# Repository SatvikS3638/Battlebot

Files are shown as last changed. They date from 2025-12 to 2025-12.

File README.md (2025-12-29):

# Project Overview

This project documents the design of a 15 kg combat robot (battlebot) for Robowars‑style competitions, focusing on mechatronic system design, drivetrain sizing, weapon actuation, and electrical subsystem selection. The goal was to design a robust, remotely operated, two‑wheeled drum‑spinner robot that can traverse the arena quickly, survive impacts, and reliably deliver weapon strikes within the competition budget and rules.

This project is hosted at : [https://github.com/SatvikS3638/Battlebot]

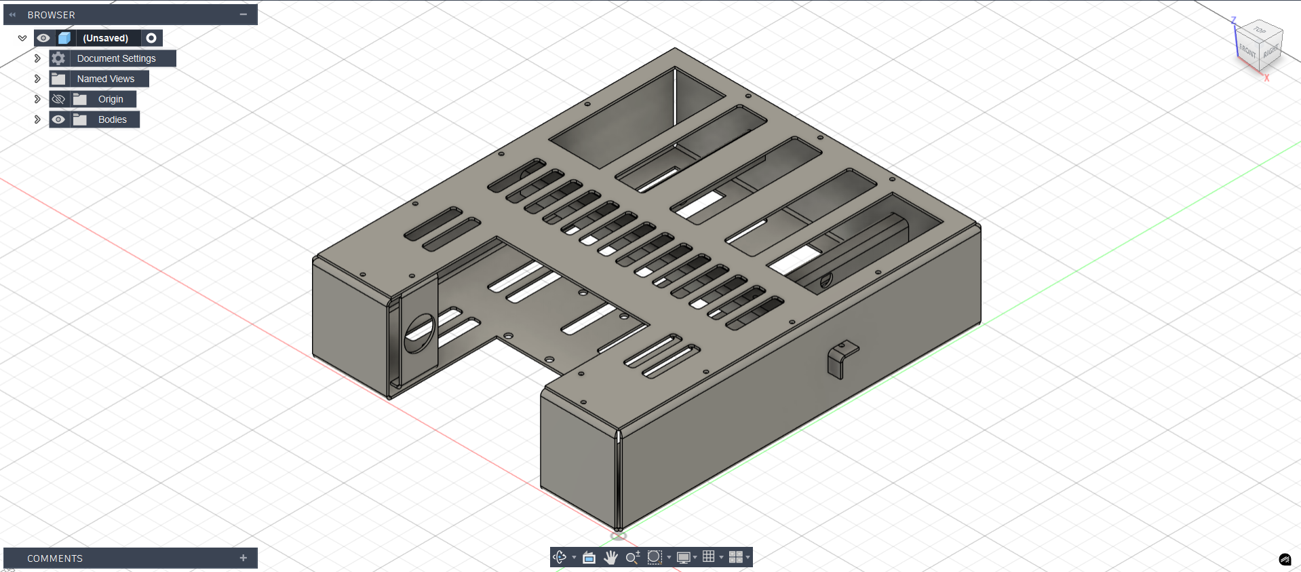
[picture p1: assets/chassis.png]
Combat Robot Chassis
 

# System Requirements
## Competition and Performance Targets
* Maximum robot weight: 15 kg (Robowars class limit).
* Locomotion: Two‑wheel differential drive with independent wheel motors.
* Weapon: Front‑mounted horizontal drum spinner capable of delivering high‑energy impacts.
* Mobility target: Traverse the arena diagonal (approximately 16 ft) in about 6 seconds, with adequate acceleration for combat maneuvers.

## Mechanical Constraints
* Maximum practical wheel diameter identified from available COTS wheels: 100 mm (10 cm).
* Wheel width options considered: approximately 20 mm and 46 mm, chosen for robustness and traction in a combat environment.
* Drum spinner radius constrained to be no larger than wheel radius (≈50 mm) to maintain ground clearance and packaging compatibility

## Electrical and Control Constraints
* Remote control via RC transmitter–receiver pair with at least 3 channels (2 drive channels + 1 weapon channel).
* Power system using LiPo chemistry for high discharge rates and low weight.
* Use of COTS ESCs or motor drivers compatible with selected brushed/brushless motors and current requirements.

# Drivetrain Design
## Velocity and RPM Calculations
To ensure adequate mobility, the required linear speed V was computed assuming the robot must cross the diagonal of the arena in about 6 seconds. For a 16 ft square arena, this yields a required velocity of approximately 1.15 m/s. 
For a wheel radius R ≈ 0.05 m (10 cm diameter), the required wheel rotational speed N is: 
$$N=\frac{V}{2\pi R}≈7.32rev/s≈220rpm$$ 

This RPM served as a target for the wheel motor selection so that the bot can meet the agility requirement without over‑gearing the drivetrain.

## Acceleration Requirement
Typical combat robot guidelines suggest an acceleration magnitude on the order of half the target velocity over one second. Using this rule of thumb, a design acceleration of approximately 0.57 m/s² was adopted for sizing the drivetrain torque.

## Traction and Torque Estimates
Assuming a maximum robot weight of 15 kg and a worst‑case engagement where the effective load on the wheels can temporarily double (up to 30 kg), the load per wheel was estimated at about 7.5 kg for a four‑wheel configuration. Using this load and the 50 mm wheel radius, the static torque requirement per wheel was computed as approximately 0.375 Nm (37.5 Ncm).
To provide a robust margin, an additional rule from combat robotics practice was applied: each drive motor’s stall torque should be sufficient to lift the full robot weight at the wheel radius. Using a 15 kg robot, the required stall torque per motor becomes:
$$T_{stall}=mgr=15x9.8x0.05≈7.35Nm$$
This requirement drove the choice of geared drive motors with sufficiently high stall torque.

## RMF (Robot Motor Factor) Check
The drivetrain design was validated using an online Robot Motor Factor (RMF) calculator, which consolidates robot weight, wheel radius, and speed into a single metric. With the chosen parameters, the RMF requirement was around 6.9 kg·m·rev/s, and motors meeting or exceeding this RMF were considered acceptable.

# Weapon (Drum Spinner) Design

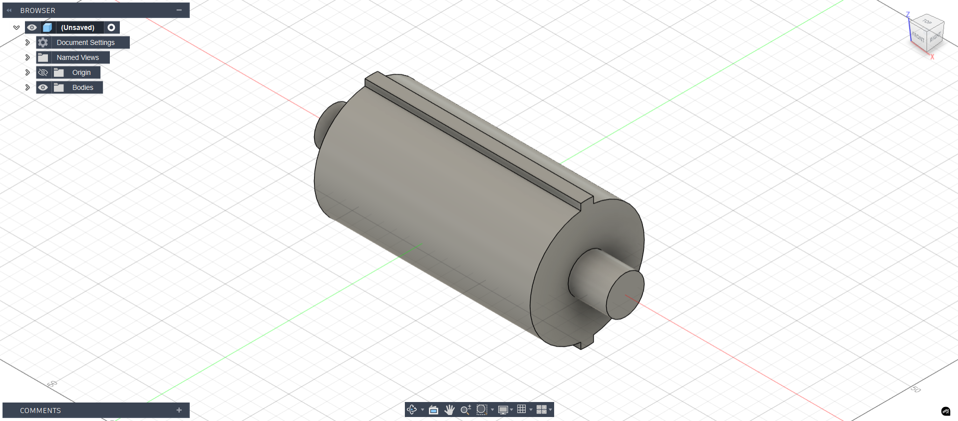
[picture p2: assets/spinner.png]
Drum Spinner Design
 

## Worst‑Case Load Modelling
The drum spinner motor was sized for an extreme case where the entire opponent robot’s weight rests on the drum, even though this scenario is unlikely in practice. Taking an opponent mass of up to 15 kg and assuming a friction coefficient up to 1, the maximum normal force on the drum can be approximated as:
$$F_{max}≈2xM_{2}g≈294N$$
Here, a safety factor of 2 was included to account for dynamic impacts and uncertainties.
With the drum radius constrained to 50 mm, the corresponding resistive torque is:
$$T_{drum}=F_{max}xr≈294x0.05≈14.7Nm$$
This torque is intentionally conservative; in practice, such a load is rarely sustained, so the design decision was to select a “very high torque” motor and prioritize robustness rather than exactly meeting this extreme torque.

## Motor Selection Strategy
The primary criteria for the drum motor were:
* High torque at operating speed to spin up the drum quickly and resist stalling during impact.
* Thermal robustness so that the motor does not overheat or fail under repeated high‑torque, high‑current operation.
* Compatibility with available ESCs and supply voltage (around 11–12 V), and alignment with overall budget limits.

# Electronics and Control System
## Motor Control (ESCs and Drivers)
For brushless motors, compact drone‑type ESCs rated at 40 A and above were considered, offering good availability and cost‑effectiveness in the sub‑₹1000 range per unit. The ESC continuous current ratings were chosen to exceed the maximum motor current at stall or peak load, and physical size was considered to ensure adequate heat dissipation during matches.
For brushed motors, high‑current ESCs were harder to source locally within budget, so a microcontroller‑plus‑motor‑driver architecture was evaluated. In this configuration:
*  A microcontroller (e.g., Arduino Uno) handles RC signal decoding and PWM generation.
*  Dual and single high‑current DC motor drivers (e.g., 13 A continuous, 30 A peak modules) drive the wheel and weapon motors.

## Power System (Batteries)
LiPo batteries were selected for their high energy density and discharge capability. A typical option considered was a 3‑cell (11.1 V) LiPo pack with capacity up to 3000 mAh as a modular solution, and a single larger 8000 mAh 3S pack as an integrated high‑capacity option.
Key design considerations:
* Discharge rating (C‑rating) sufficient to supply combined peak current of drive and weapon systems over the match duration.
* Trade‑off between using multiple smaller cells for better packaging and weight distribution versus a single larger pack for simplicity.
* Overall battery cost and availability in the Indian market.

## RC Transmitter and Receiver
A 2.4 GHz RC system with at least 6 channels was selected to provide headroom for drive, weapon, and potential future auxiliaries. An affordable Flysky transmitter–receiver pair was chosen, offering sufficient functionality for combat robots while remaining accessible for student teams.
Important RC system features:
* Matching protocol between transmitter and receiver for reliable communication.
* Built‑in BEC on ESCs or dedicated BEC to power the receiver at the appropriate voltage and current.
* Support for forward, reverse, and mixed control (tank steering), plus a compliant trip/failsafe mechanism as per competition safety rules.

# Component Selection and Budget
## Final Component List (Representative)
The following components were shortlisted based on the above requirements and calculations:
* RC System: Flysky CT6B 2.4 GHz 6‑channel transmitter with receiver, providing sufficient channels for two drive motors and one weapon motor.
* Wheel Motors: Two planetary geared DC motors satisfying the 7.35 Nm stall torque requirement and RMF criterion, with per‑motor costs in the ₹2000–₹2500 range.
* Weapon Motor: A high‑torque 12 V planetary gear motor (e.g., 100 rpm, ≈294 N·cm rated torque) chosen to deliver strong drum acceleration and sustained torque.
* Motor Drivers/Controllers:
  - Option A: Three 50 A ESCs for a brushless architecture (2 drive + 1 weapon), using drone‑grade ESCs.
  - Option B: Microcontroller (e.g., Arduino Uno) plus dual and single high‑current DC motor driver modules for a brushed architecture.
* Battery: Either a modular 3S LiPo setup around 11.1 V and 3000 mAh per pack, or a single 3S 8000 mAh pack, selected based on weight and runtime trade‑offs.

Approximate line‑item prices were compiled from local robotics and e‑commerce vendors to ensure the entire system fits within a student competition budget, with motor and battery choices having the largest cost impact.

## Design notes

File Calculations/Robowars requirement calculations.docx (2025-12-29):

# Battlebot Design Calculations

Satvik Sarode

Watch the ‘Team just cause electronics’ combat robot electronics series.

1. Wheel motors

-The largest and sturdiest robot wheels that can be found on the internet are 10 cm in dia.

The weight of the bot can be maximum 15 kg, even if during engagement the weight on the wheel doubles, i.e. becomes 30 kg, with a distributed load of 7.5 kg on all four wheels, the max. Torque on each wheel = .375 Nm or 37.5 Ncm.

This link has a good explanation of robot velocity, rpm and subsequent torque requirements.

https://www.societyofrobots.com/mechanics_dynamics.shtml

Wheel links:

https://roboticsdna.in/product/104-6mm-wheel/ 4.6 cm thickness

https://roboticsdna.in/product/102-wheel/ 2 cm thickness

Max rpm has been calculated from assuming that the diagonal of the arena has to be traversed in 6 seconds. V = (16ft*sq.rt.(2))/7 = 1.14945 m/s

N = V/2*pi*R = 7.3177 rev/s = 219.5 rpm

For a typical robot on flat terrain, magnitude of accl. Is suggested to be half of that of velocity, a = 0.5747 m2/s

Torque = force *wheel radius

“My personal rule is if you have 2 motors on your robot, make sure the stall torque on each is enough to lift the weight of your entire robot times your wheel radius.” - society of robots combat electronics guide

By this, stall torque = 15 x 9.8 x 0.05 = 7.35 Nm

https://www.societyofrobots.com/RMF_calculator.shtml

The above inputs has been input into RMF calculator from societyofrobots. Any motor that satisfies the RMF requirement is suitable for us. (Even a 500 rupee motor does satisfy our requirements)

RMF = 6.9 kgmr/s

Brushed Motors that satisfy this requirement are in the 2000-2500 rupee range

Brushless motors do that for half the price.

2. Drum spinner motors

Since these will engage with the other bot, we need motors which will not heat up or melt upon reaching high temperatures under a large amount of torque requirement.

The drum spinner motor needs to be such that even if the full weight of the opponent bot is placed on it, it will still overcome it and rotate, damaging the other robot. Drawing a very crude FBD, this represents the extreme situation when the other bots weight is completely on the drum spinner, which will never actually happen.

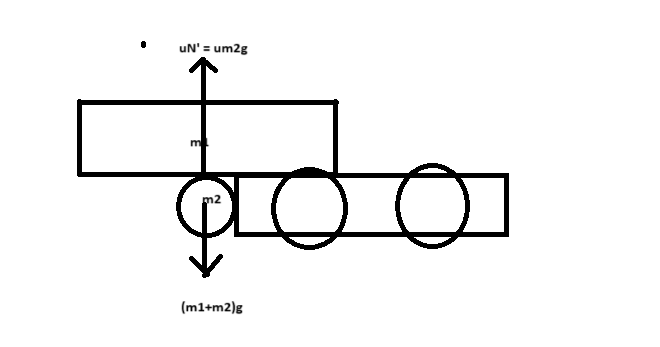
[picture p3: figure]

Max. weight on drum spinner = uM2g where M2 can be maximum 15 kg, and u is rarely greater than 1, m2g = 147, with a safety factor of 2, it can be maximum 294 N.

Torque = 294 x radius of drum spinner, which cannot be larger than the radius of the wheels = 294 x 0.05 = 14.7 Nm

Which is way too high,(Thus the entire calculation you read is redundant) ,so we will just need a very powerful (high torque) motor.

3. ESC

Amp rating should be more than amps drawn by motor at max load, and the ones which are very small will not provide the amperage that they have been specified for, since too less area for heat dissipation.

ESCs also have an inbuilt BEC for receivers, check the voltage and current rating on that.

Good drone escs rated 40 amps under 1000 rupees are available if we use brushless motors.

4. Batteries

https://www.youtube.com/watch?v=arOXg7y6r8k

Aman bhaiya suggested using individual cells instead of single large batteries to reduce weight.

LiPo batteries of 11.1V and upto 3000mAh are available at around 2000 rupees.

We need to pay attention to the discharge rating to make sure that our bot lasts the amount of time required for our competition.

5. Receiver and Transmitter

The receiver and the transmitter need to operate under the same protocol. Battlebots

need RC systems with at least 3 channels to operate the 2 drive motors and a weapon motor.

The most popular affordable transmitter brand is Flysky, which is not very high end, but recommended for beginners.

Receivers are generally powered by an ESC, so the current rating of ESC should be accordingly decided. Must look for receivers with forward/reverse/sideways control, and also a compliant trip circuit.

If we use brushless motors, we can just use R/C equipment used for drones.

After actually having the components in hand, we need to do binding and mixing to operate it properly.

Final components list and budget:

1. Flysky CTB6 transmitter with receiver

https://robu.in/product/ct6b-flysky-2-4ghz-6ch-transmitter-wfs-r6b-receiver-mode-2/

2535/-

If we opt for Brushed motors, I have listed the ones we can buy below, but brushless motors are in general more efficient, and will last longer, and have a lot of cheap escs available online. But I can't seem to find BLDCs online that will fit in our budget.

2. Wheel motors:

https://robu.in/wp-content/uploads/2020/10/performance-PG45775128000-19.2K-1.pdf

2299 x 2 =4598/-

3. Weapon motor:

https://robu.in/product/orange-planetary-gear-dc-motor-12v-100-rpm-294-3-n-cm-pgm45775-71-2k/

2399/-

4. Controller

We will either need 3 ESCs of 50 amps each or microcontrollers and dual and single motor drivers.

For brushed motors, escs are not available online, thus microcontroller+motor driver is a safer, and cheaper option.

https://robu.in/product/dual-channel-enhanced-13amp-dc-motor-driver-30a-peak/

1900/-

https://www.amazon.in/permanent-guarantee-Arduino-Uno/dp/B0044X2E5S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

2950/-

https://robokits.co.in/motor-drives-drivers/rhino-cytron-dc-motor-drivers/cytron-dc-motor-driver-5v-30v-13amp-md10c-original

1121/-

5. Battery :

If we want a single battery :

https://robu.in/product/orange-8000mah-3s-30c60c-lithium-polymer-battery-pack-lipo/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

5250/-

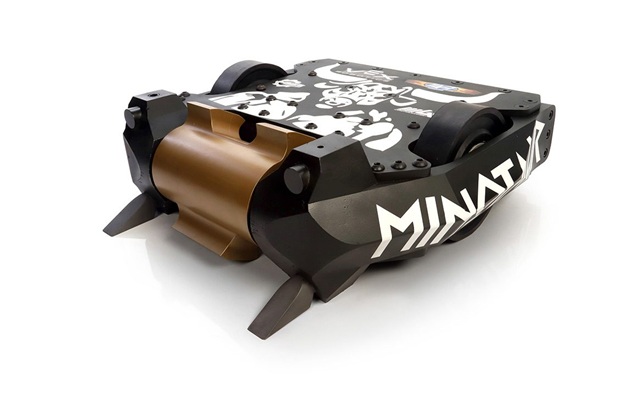
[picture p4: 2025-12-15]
assets/Minotaur-Bot-S2019-1140x760.jpg

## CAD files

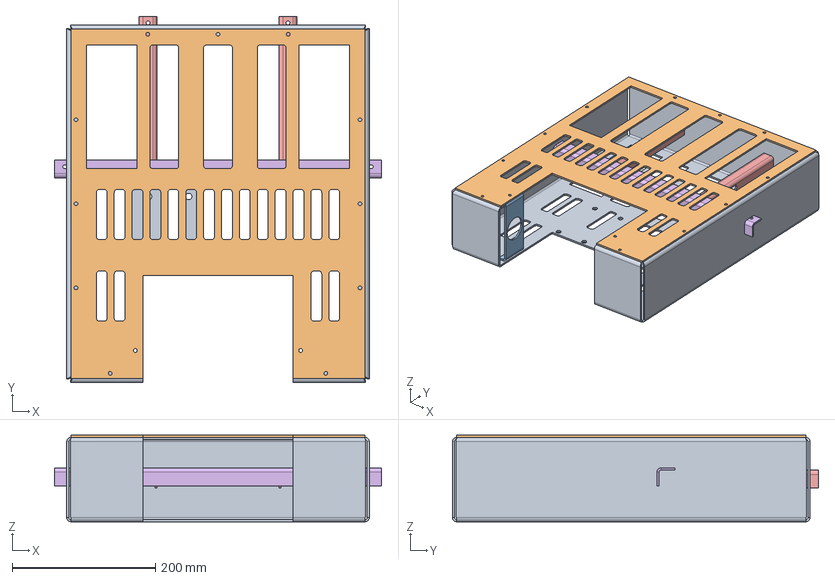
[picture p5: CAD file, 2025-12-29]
Design/Complete frame.step
457.0 x 512.0 x 121.0 mm

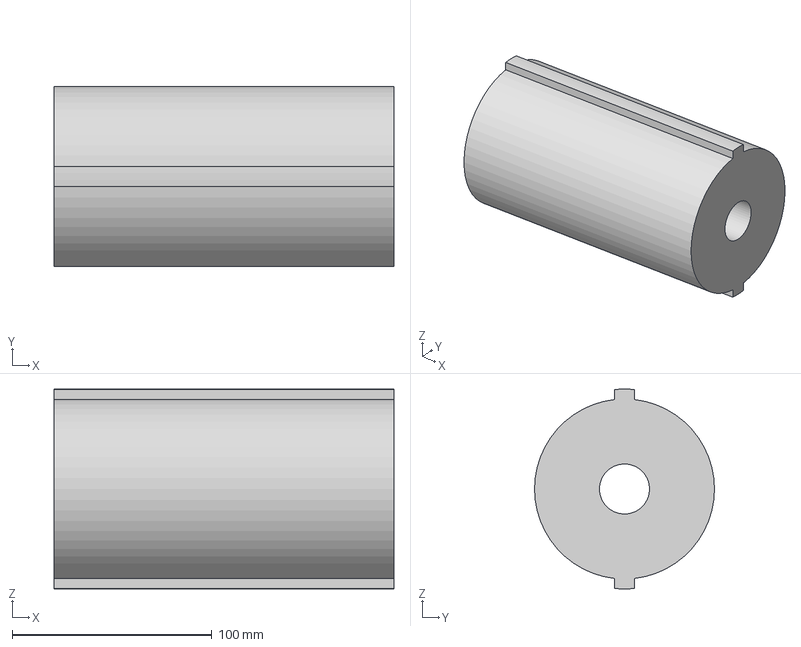
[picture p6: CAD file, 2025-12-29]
Design/Weapon spinner.step
170.0 x 90.0 x 99.9 mm

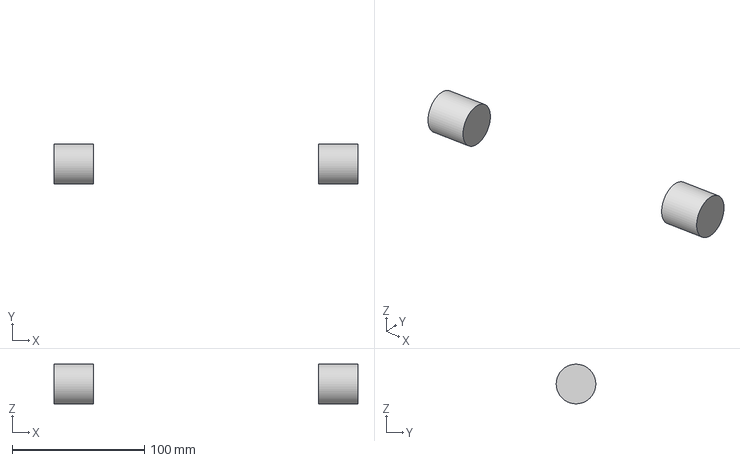
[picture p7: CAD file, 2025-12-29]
Design/Weapon shaft ends.step
230.0 x 30.0 x 30.0 mm

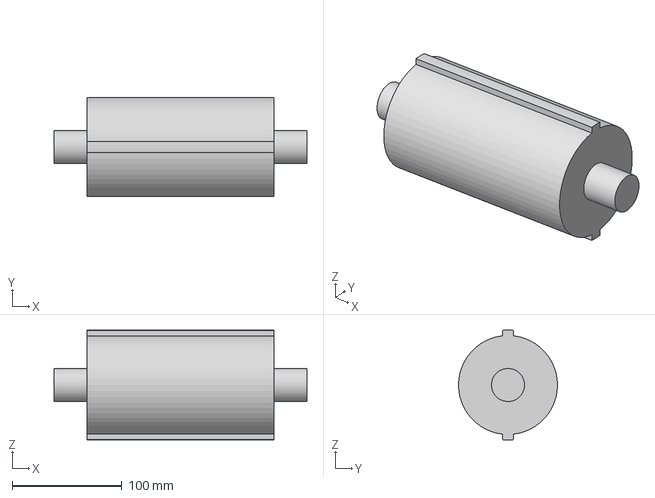
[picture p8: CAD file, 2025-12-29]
Design/Weapon combined.step
230.0 x 90.0 x 99.9 mm

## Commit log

2025-12-15 Revise README with initial considerations and selections
    Updated the README to include initial considerations and details about weapon mechanism and control device selection.
2025-12-18 Update README with detailed design specifications
    Expanded sections on motor selection, electronics, and component budget for the drum spinner design.
2025-12-29 Fix formatting of torque equation in README
2025-12-29 Add images to README for robot design documentation
    Added images of the combat robot chassis and drum spinner design to the README.
